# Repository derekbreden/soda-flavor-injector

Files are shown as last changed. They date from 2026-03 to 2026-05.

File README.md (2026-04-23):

# Soda Flavor Injector

ESP32 + RP2040 + ESP32-S3 project that injects flavoring concentrate into cold carbonated water from an under-counter carbonator. Peristaltic pumps duty-cycle based on real-time flow meter readings to maintain consistent flavor strength. A round LCD display shows which flavor is selected, and a separate rotary touchscreen display lets you change flavor images and ratios at runtime.

**[How this got built](how-this-got-built.md)** — the full story, from a failed SodaStream to a working soda machine.

<p align="center">
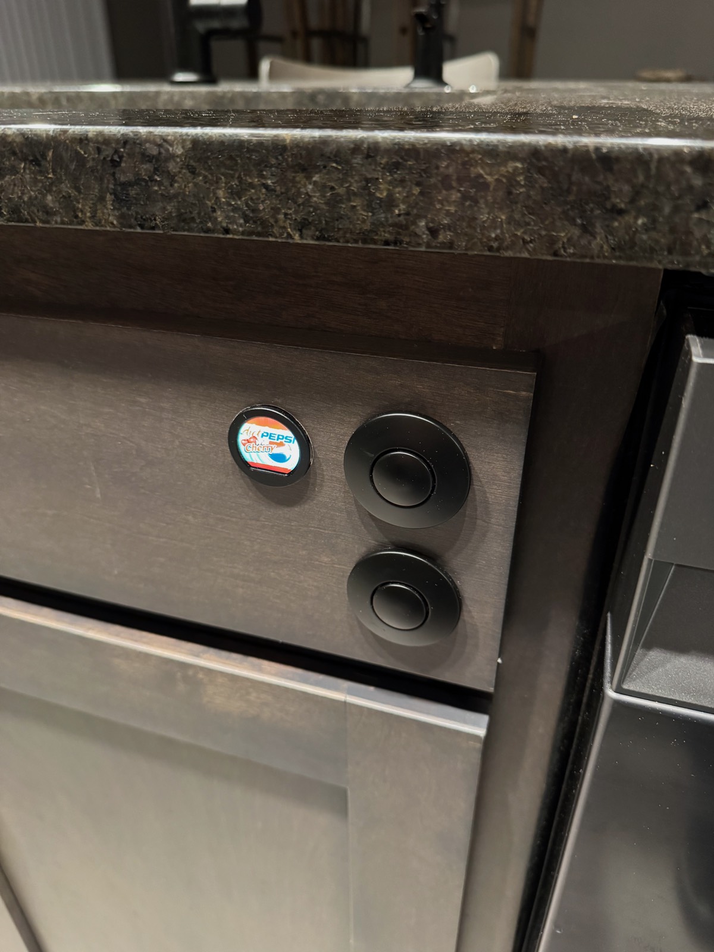
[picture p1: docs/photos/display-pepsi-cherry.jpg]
Front panel showing LCD display with Diet Pepsi Cherry logo and air switch buttons
  
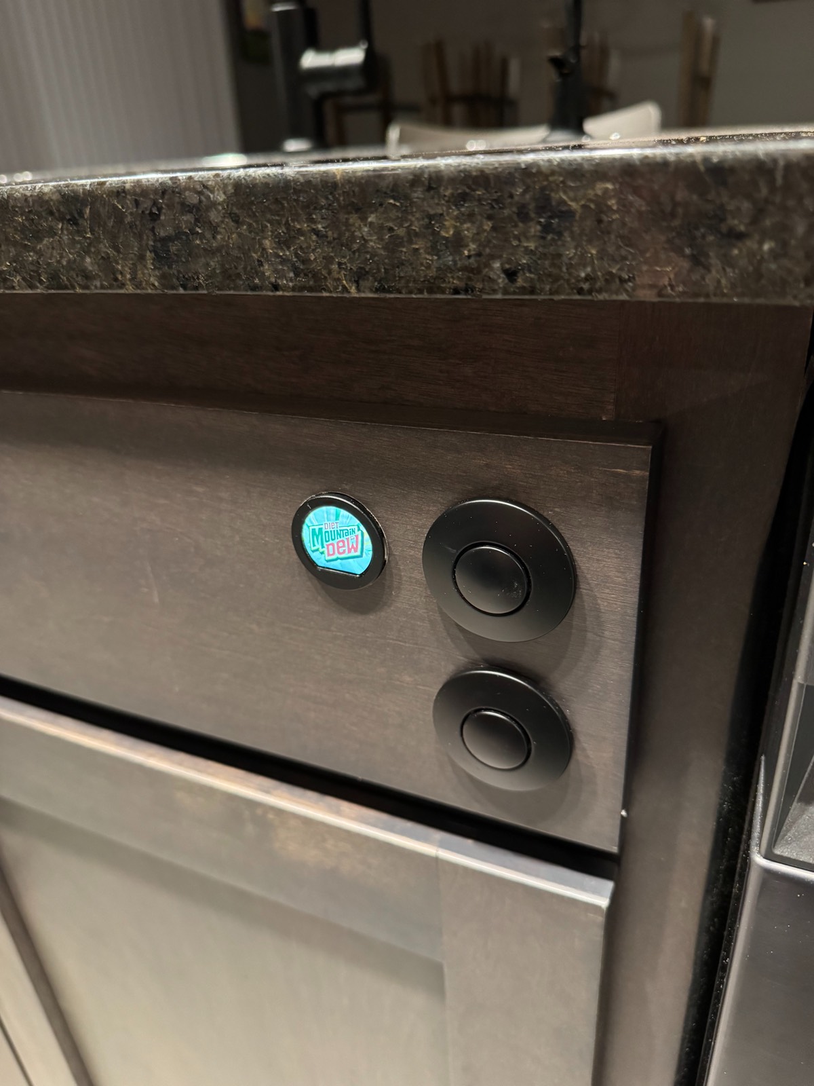
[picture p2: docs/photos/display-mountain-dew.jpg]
Front panel showing LCD display with Diet Mountain Dew logo and air switch buttons
  
</p>
<p align="center"><em>The RP2040 round LCD shows the active flavor. An air switch button toggles between flavors.</em></p>

https://github.com/user-attachments/assets/ddd9bcfd-567e-414a-80be-4f5125431bac

<p align="center"><em>Changing flavor images and ratios on the config display, then pouring a glass with both flavors.</em></p>

## How It Works

Cold carbonated water flows from an under-counter carbonator through a dispenser faucet. When you open the faucet, a flow meter detects water movement and the system automatically kicks in:

1. A solenoid valve opens (it stays closed between uses to prevent backflow and keep the lines primed)
2. A peristaltic pump injects concentrate from a collapsible reservoir
3. The pump duty-cycles on/off proportionally to the detected flow rate
4. Concentrate meets the water stream at the faucet spout

A toggle switch (an air switch) selects between two flavors. The small LCD display updates to show which flavor is active.

<p align="center">
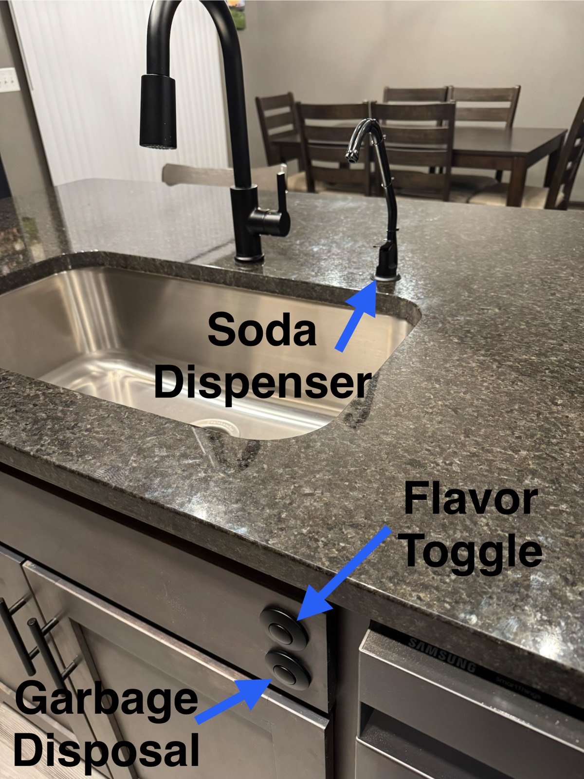
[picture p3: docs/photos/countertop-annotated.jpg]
Kitchen countertop showing soda dispenser faucet and flavor toggle switch
  
</p>
<p align="center"><em>The countertop: a dedicated dispenser faucet and a flavor toggle air switch.</em></p>

### Under the Counter

Everything lives inside the sink cabinet:

<p align="center">
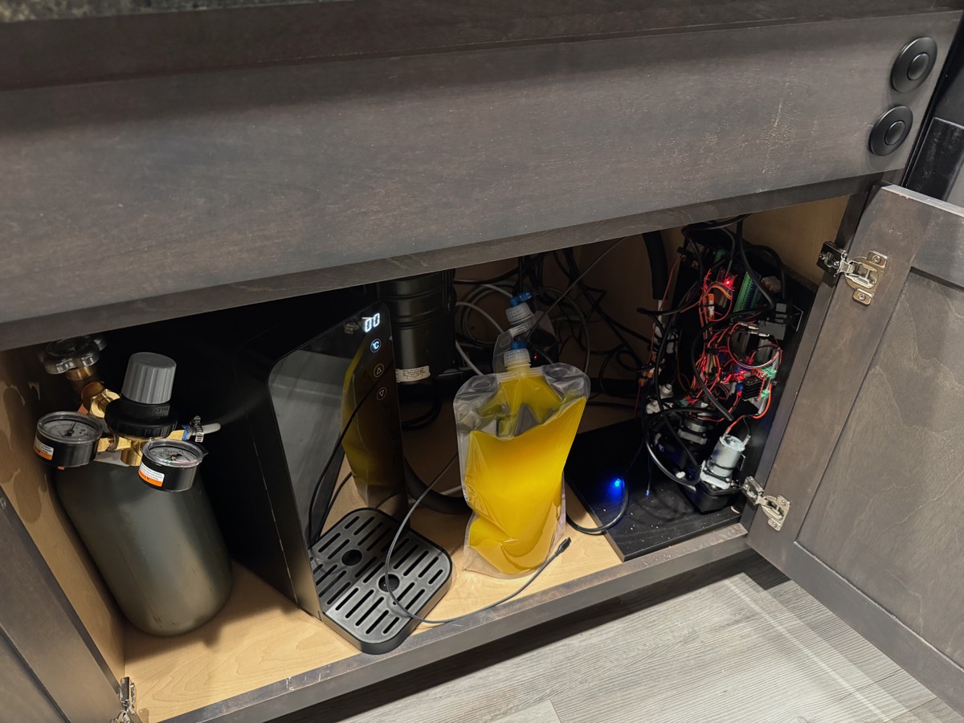
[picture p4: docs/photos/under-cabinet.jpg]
Under-cabinet view showing CO2 tank, carbonator, concentrate bag, and control panel
  
</p>
<p align="center"><em>Left to right: CO2 tank with dual-gauge regulator, Lilium carbonator, Platypus bag filled with concentrate, and the control panel with pumps and valves.</em></p>

Silicone concentrate lines are zip-tied to the outside of the faucet gooseneck:

<p align="center">
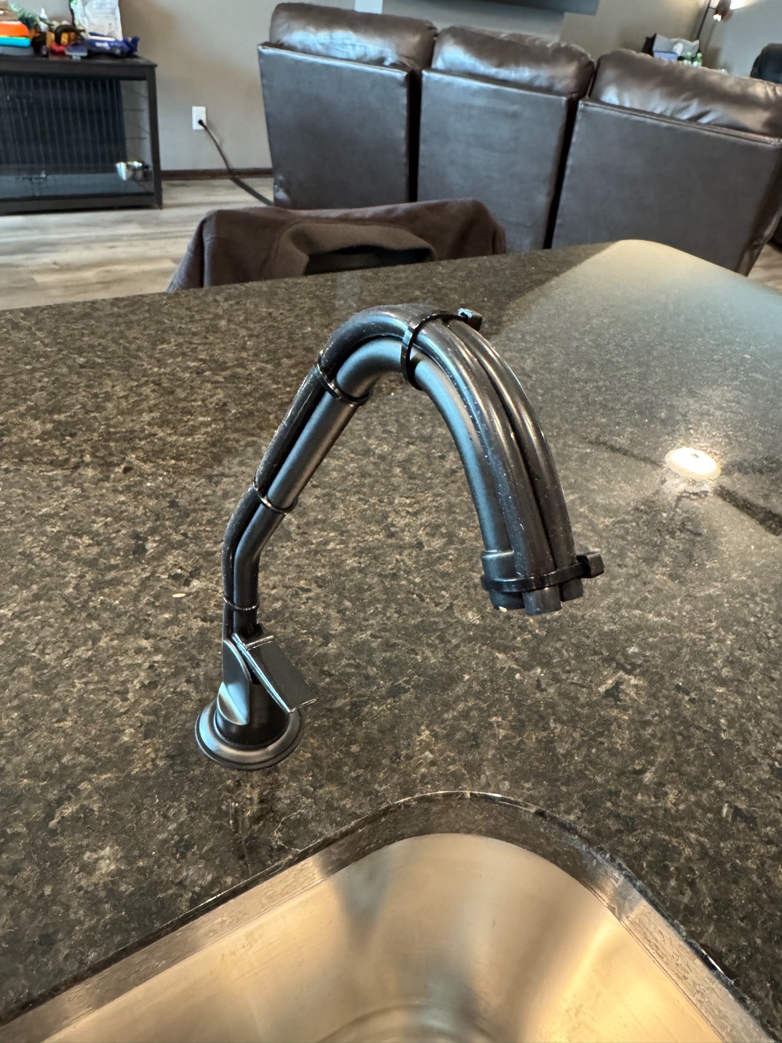
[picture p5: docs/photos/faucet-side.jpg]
Side view of dispenser faucet with silicone tubes bundled along the gooseneck
  
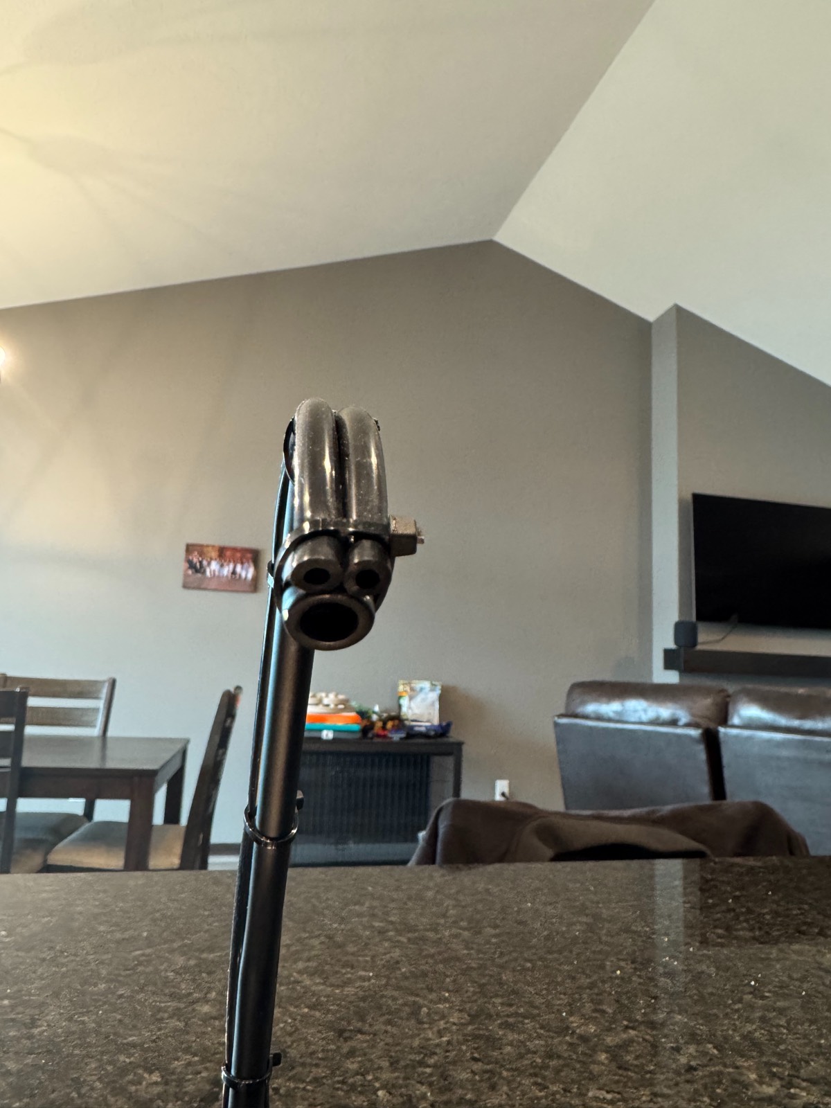
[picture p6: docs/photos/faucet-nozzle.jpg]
Close-up of faucet nozzle showing multi-tube dispensing design
  
</p>

### Architecture

The system runs on three microcontrollers:

- **ESP32** — Main controller. Reads the flow meter, drives pumps and valves via L298N motor drivers, manages the pump state machine, stores config in LittleFS, and coordinates the other boards over UART using TinyProto (HDLC full-duplex reliable delivery).
- **RP2040** (Waveshare RP2040-LCD-0.99) — Display controller. Shows the selected flavor logo on a 128x115 round LCD. Reads the same physical toggle switch for instant visual feedback.
- **ESP32-S3** (Meshnology 1.28" Round Rotary Display) — Config display. A 240x240 round touchscreen with a rotary encoder for changing flavor images and ratios at runtime. Also serves as a BLE bridge between the iOS app and ESP32. Syncs config to the ESP32 over UART.

```
                        ┌─────────────────────┐
  Carbonated Water ───→ │ Flow Meter (GPIO 23) │
                        └──────────┬──────────┘
                                   │ pulses
  ┌───────────────┐     ┌──────────▼──────────┐
  │ ESP32-S3      │     │   ESP32 Controller   │
  │ Config Display│     │                      │
  │ 240x240 touch │◄───►│  Pump State Machine   │
  │ + encoder     │UART │  IDLE → ON → OFF ──→ │──(cycle repeats)
  │               │     │    └── COOLDOWN       │
  └───────────────┘     │    └── PRIME (via UI)  │
                        └──┬────────┬────────┬─┘
                           │        │        │
                      UART │   L298N A  L298N B
                           │   ┌────┴┐  ┌───┴──┐
                           │   │Pump1│  │Pump2 │
              ┌────────────▼┐  │Valve│  │Valve │
              │ RP2040 LCD  │  └─────┘  └──────┘
              │ 128x115 px  │
              │ flavor logo │
              └─────────────┘
```

### Pump Control

The pump doesn't just run at a fixed speed. It duty-cycles (on/off/on/off) with timing that adapts to how fast water is flowing:

| Flow Rate | On Time | Off Time | Duty Cycle |
|---|---|---|---|
| Slow (1 pulse/50ms) | 50ms | 600ms | ~8% |
| Full (6 pulses/50ms) | 200ms | 300ms | ~40% |

This is further scaled by a per-flavor **ratio** parameter (configurable at runtime via the config display):
- Ratio 20 — tuned for SodaStream concentrates (1:20 concentrate-to-water)
- Ratio 6 — for bag-in-box syrup (traditional fountain ratio)

## Parts List

Nearly everything was sourced from Amazon Prime. The only exception is the carbonated water machine.

### Electronics

| Part | Purpose |
|---|---|
| [ESP32-DevKitC-32E](https://www.amazon.com/dp/B09MQJWQN2) | Main controller |
| [ESP32 DIN Rail Breakout Board](https://www.amazon.com/dp/B0BW4SJ5X2) | Clean wiring for ESP32 GPIOs |
| [Waveshare RP2040 Round LCD (0.99")](https://www.amazon.com/dp/B0CTSPYND2) | Flavor display (128x115 GC9107) |
| [Meshnology ESP32-S3 1.28" Round Rotary Display](https://www.amazon.com/dp/B0G5Q4LXVJ) | Config display (240x240 GC9A01A, touch + encoder) |
| [L298N Dual H-Bridge Motor Driver](https://www.amazon.com/dp/B0C5JCF5RS) x2 (link is a 4-pack) | Drive pumps and solenoid valves |
| [12V 2A Power Supply](https://www.amazon.com/dp/B0DZGTTBGZ) | Powers pumps and valves |

### Pumps and Valves

| Part | Purpose |
|---|---|
| [Kamoer Peristaltic Pump (400ml/min, 12V)](https://www.amazon.com/dp/B09MS6C91D) x2 | Dispense flavor concentrate |
| [Beduan 12V Solenoid Valve (1/4")](https://www.amazon.com/dp/B07NWCQJK9) x2 | Prevent backflow, keep concentrate lines primed |

### Sensors and Switches

| Part | Purpose |
|---|---|
| [DIGITEN G3/8" Hall Effect Flow Sensor](https://www.amazon.com/dp/B07QQW4C7R) | Measure water flow rate |
| [KRAUS Garbage Disposal Air Switch (Matte Black)](https://www.amazon.com/dp/B096319GMV) | Flavor toggle (countertop safe, no electricity) |

### Plumbing

| Part | Purpose |
|---|---|
| [Westbrass Cold Water Dispenser Faucet (Matte Black)](https://www.amazon.com/dp/B07KH285GJ) | Dispensing tap at the counter |
| [Platypus 2L Collapsible Bottle](https://www.amazon.com/dp/B000J2KEGY) x2 | Flavor concentrate reservoirs |
| [Platypus Hydration Drink Tube Kit](https://www.amazon.com/dp/B07N1T6LNW) | Tubing + bite valve for reservoirs |
| 1/4" OD Hard Tubing (PE/PU) | All internal plumbing connections (John Guest push-to-connect fittings) |
| [Silicone Tubing (1/8" ID x 1/4" OD)](https://www.amazon.com/dp/B0BM4KQ6RT) | Pump heads, faucet cosmetic run, cable gland pass-throughs, vibration-dampening segments |
| [Waterdrop 15UC-UF Inline Water Filter](https://www.amazon.com/dp/B085G9TZ4L) | Filters water before carbonation |

### Flavor Concentrates

| Part | Notes |
|---|---|
| [SodaStream Pepsi Wild Cherry Zero Sugar](https://www.amazon.com/dp/B0G4NRDQB8) | Default ratio 1:20 |
| [SodaStream Diet MTN Dew](https://www.amazon.com/dp/B0CS191QMW) | Default ratio 1:20 |

### Wiring and Connectors

| Part | Purpose |
|---|---|
| [Dupont Jumper Wires (120-pack M/F, M/M, F/F)](https://www.amazon.com/dp/B0BRTJXND9) | Board-to-board connections |
| [Female Spade Crimp Terminals (60-pack)](https://www.amazon.com/dp/B0B9MZJ2ML) | Motor and valve connections |
| [Male Quick Disconnect Spade Connectors (100-pack)](https://www.amazon.com/dp/B01MZZGAJP) | Motor and valve connections |

### Mounting and Hardware

| Part | Purpose |
|---|---|
| [Zip Ties (200-pack)](https://www.amazon.com/dp/B0BC1VH4XB) | Secure tubing to faucet, cable management |
| [12"x24" Laminate Shelf](https://www.homedepot.com/p/328395734) | Cut in half and screwed together as mounting panel |
| [#8 x 1/2" Wood Screws (100-pack)](https://www.homedepot.com/p/204275505) | Mount components to panel |
| ~~[Pre-wired 12V LEDs (120-pack, 6 colors)](https://www.amazon.com/dp/B07PVVL2S6)~~ | ~~Flavor indicator LEDs~~ (removed — RP2040 display replaced LEDs) |

### Carbonated Water

| Part | Purpose |
|---|---|
| [Lilium Under-Sink Carbonated Water Dispenser](https://liliumfaucet.com/products/under-sink-carbonated-soda-maker-sparkling-water-dispenser-with-3-way-faucet) | Cold carbonated water source (not from Amazon) |
| [TAPRITE Dual-Gauge CO2 Regulator](https://www.amazon.com/dp/B00L38DRD0) | CO2 pressure regulation |
| 5 lb CO2 Tank + First Refill | CO2 source (refills ~$25 at welding/homebrew shops) |

### Tools

Most builders will already have these on hand.

| Tool | Purpose |
|---|---|
| [RYOBI ONE+ 18V Drill/Driver Kit](https://www.homedepot.com/p/326680222) | Drilling and driving screws |
| [RYOBI Drill Bit Set (15-piece)](https://www.homedepot.com/p/315853368) | General-purpose drill bits |
| [Milwaukee 1-1/4" Hole Dozer with Arbor](https://www.homedepot.com/p/202327734) | Countertop holes for faucet and air switch |
| [Wiss 10" Tradesmen Scissors](https://www.homedepot.com/p/313487663) | Cutting tubing and zip ties |
| [Husky Precision Screwdriver Set (7-piece)](https://www.homedepot.com/p/302435926) | Electronics work |
| [Klein Tools 3005CR Ratcheting Crimper (10-22 AWG)](https://www.amazon.com/dp/B07WMB61J5) | Crimp spade terminals |
| [Apple USB-C to USB-C Cable (2m)](https://www.amazon.com/dp/B0DCH5B2HF) | Flash the RP2040 |
| [LISEN USB-C to Micro USB Cable (2-pack)](https://www.amazon.com/dp/B0D3BXM91B) | Flash the ESP32 |

## Wiring

<p align="center">
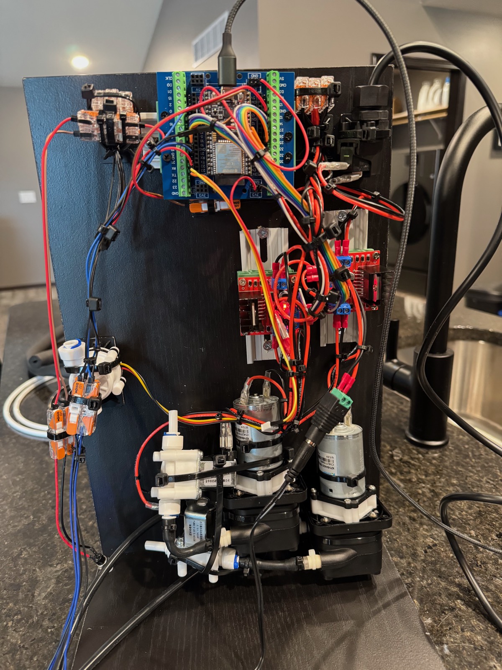
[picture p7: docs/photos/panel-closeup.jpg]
Control panel showing ESP32 on DIN rail breakout, two L298N motor drivers, peristaltic pumps, and solenoid valves
  
</p>
<p align="center"><em>The control panel: ESP32 on a DIN rail breakout board (top), two L298N motor drivers (red boards), two Kamoer peristaltic pumps, and two solenoid valves (bottom).</em></p>

### ESP32 Pin Assignments

**L298N Board A (Flavor 1):**

| Function | GPIO | Notes |
|---|---|---|
| ENA (pump PWM) | 33 | |
| IN1 (pump dir) | 25 | |
| IN2 (pump dir) | 26 | |
| ENB (valve on/off) | 12 | IN3/IN4 hardwired on board (IN3→5V, IN4→GND) |

**L298N Board B (Flavor 2):**

| Function | GPIO | Notes |
|---|---|---|
| ENA (pump PWM) | 19 | |
| IN1 (pump dir) | 18 | |
| IN2 (pump dir) | 5 | |
| ENB (valve on/off) | 4 | IN3/IN4 hardwired on board (IN3→5V, IN4→GND) |

**Inputs and Communication:**

| Function | GPIO | Notes |
|---|---|---|
| Flavor toggle switch | 13 | Air switch, INPUT_PULLUP |
| Flow meter | 23 | Hall effect, FALLING edge interrupt |
| Display UART TX | 32 | 115200 baud, TinyProto HDLC to RP2040 (Serial2) |
| Display UART RX | 35 | 115200 baud, TinyProto HDLC from RP2040 |
| Config UART TX | 15 | 115200 baud, TinyProto HDLC to ESP32-S3 (Serial1) |
| Config UART RX | 34 | 115200 baud, TinyProto HDLC from ESP32-S3 (input-only pin) |

| RTC SDA (DS3231) | 21 | I2C, Wire library |
| RTC SCL (DS3231) | 22 | I2C, Wire library |

**Freed GPIOs** (LEDs removed, valve IN3/IN4 hardwired): 2, 27, 17, 16. GPIOs 27 and 17 are reserved for clean cycle solenoids (L298N Board #3).

### RP2040 Pin Assignments

| Function | GPIO | Notes |
|---|---|---|
| Flavor toggle switch | 29 | Same physical switch as ESP32 |
| UART TX (to ESP32) | 27 | PIO-based serial, 115200 baud, TinyProto HDLC |
| UART RX (from ESP32) | 26 | PIO-based serial, 115200 baud, TinyProto HDLC |
| LCD DC | 8 | Fixed on board |
| LCD CS | 9 | Fixed on board |
| LCD CLK | 10 | Fixed on board |
| LCD DIN | 11 | Fixed on board |
| LCD RST | 13 | Fixed on board |
| LCD Backlight | 25 | Fixed on board |

### ESP32-S3 Pin Assignments (Meshnology 1.28")

All pins are fixed by the board design.

| Function | GPIO | Notes |
|---|---|---|
| LCD SPI MOSI | 11 | GC9A01A, 240x240 |
| LCD SPI SCLK | 10 | |
| LCD CS | 9 | |
| LCD DC | 3 | |
| LCD RST | 14 | |
| LCD Backlight | 46 | |
| Display power 1 | 1 | Must be set HIGH |
| Display power 2 | 2 | Must be set HIGH |
| Touch SDA | 6 | CST816D, Wire1 I2C |
| Touch SCL | 7 | |
| Touch INT | 5 | |
| Touch RST | 13 | |
| Encoder CLK | 45 | |
| Encoder DT | 42 | |
| Encoder BTN | 41 | |
| RGB LEDs | 48 | WS2812 x5 (unused) |
| UART TX (J34) | 43 | 115200 baud, TinyProto HDLC to ESP32 |
| UART RX (J34) | 44 | 115200 baud, TinyProto HDLC from ESP32 |

### Inter-Board Communication

All inter-MCU communication uses [TinyProto](https://github.com/lexus2k/tinyproto) at 115200 baud with HDLC full-duplex framing. Text commands are sent inside `MSG_TEXT` messages; binary image uploads use a state-based protocol where TinyProto handles fragmentation, ACKs, and retransmission internally.

**ESP32 ↔ RP2040 (bidirectional, Serial2, GPIO 32 TX / GPIO 35 RX):**

The ESP32 pushes flavor images, label mappings, and config to the RP2040. The RP2040 sends `MSG_DEVICE_READY` at boot with its image count, triggering a full sync. The ESP32 also re-syncs periodically (every 30 seconds) as a safety net.

**ESP32 ↔ ESP32-S3 (bidirectional, Serial1, GPIO 15 TX / GPIO 34 RX):**

The ESP32-S3 config display communicates with the ESP32 to read and write runtime configuration. The ESP32 is the single source of truth; config is persisted in LittleFS. The S3 also acts as a BLE bridge, forwarding commands from the iOS app to the ESP32.

Text commands are wrapped in `MSG_TEXT` messages. On boot, the S3 sends `GET_CONFIG` until the ESP32 responds. When the user changes a value on the config display (or via the iOS app over BLE), the S3 sends `SET:` followed by `SAVE`.

```
S3 → ESP32:  GET_CONFIG
ESP32 → S3:  CONFIG:F1_RATIO=20,F2_RATIO=20,F1_IMAGE=0,F2_IMAGE=1,numImages=3

S3 → ESP32:  SET:F1_RATIO=18
ESP32 → S3:  OK:F1_RATIO=18

S3 → ESP32:  SET:F1_IMAGE=2
ESP32 → S3:  OK:F1_IMAGE=2

S3 → ESP32:  SET:F1_RATIO=30
ESP32 → S3:  ERR:F1_RATIO out of range

S3 → ESP32:  SAVE
ESP32 → S3:  OK:SAVED              (persists to LittleFS)
```

Valid keys and ranges: `F1_RATIO` (6-24), `F2_RATIO` (6-24), `F1_IMAGE` (0-NUM_IMAGES-1), `F2_IMAGE` (0-NUM_IMAGES-1). The same text commands work over USB serial (115200 baud) for testing.

Boot order does not matter. The S3 retries `GET_CONFIG` until the ESP32 is ready. Both the RP2040 and S3 send `MSG_DEVICE_READY` at the end of their `setup()`, and the ESP32 uses this to trigger initial sync.

## Building and Flashing

This is a [PlatformIO](https://platformio.org/) project with three build environments.

### Flash the ESP32 (main controller)

```bash
pio run -e esp32dev -t upload
```

### Flash the RP2040 (display)

```bash
pio run -e rp2040_display -t upload
```

The RP2040 uses the [earlephilhower Arduino core](https://github.com/earlephilhower/arduino-pico) and the [GFX Library for Arduino](https://github.com/moononournation/Arduino_GFX) for the GC9107 LCD driver.

### Flash the ESP32-S3 (config display)

```bash
pio run -e esp32s3_config -t upload
```

The ESP32-S3 uses the [pioarduino platform](https://github.com/pioarduino/platform-espressif32) for Arduino core 3.x support, [LVGL v8.4](https://github.com/lvgl/lvgl) for the UI, and the [GFX Library for Arduino](https://github.com/moononournation/Arduino_GFX) for the GC9A01A display driver. A custom 64px Montserrat font (`src_config/font_ratio_64.h`) is used for the ratio edit screen.

### Adding a New Flavor Image

Flavor images can be uploaded at runtime from the iOS app over BLE. The iOS app resizes images to the correct dimensions (128x115 for RP2040, 240x240 for S3), converts them to RGB565 format, and uploads them over the framed BLE/UART protocol. Images are stored in LittleFS on each device and survive power cycles.

Factory default images are compiled into the ESP32 firmware via `board_build.embed_txtfiles` and pushed to devices on first boot.

**Adding a new factory default image:**

1. Place the source PNG in `tools/` and run `python tools/png_to_rgb565.py` to generate RGB565 binary files
2. Add the binary files to `data/` for LittleFS upload
3. Update the factory defaults configuration

## Configuration

### Runtime Config (via iOS App, Config Display, or USB Serial)

Flavor ratios and display image assignments are stored in the ESP32's LittleFS filesystem and can be changed at runtime using the ESP32-S3 config display, the iOS app (over BLE), or by sending commands over USB serial:

| Parameter | Range | Default | Description |
|---|---|---|---|
| F1_RATIO | 6-24 | 20 | Flavor 1 concentrate-to-water ratio (lower = stronger) |
| F2_RATIO | 6-24 | 20 | Flavor 2 concentrate-to-water ratio |
| F1_IMAGE | 0-N | 0 | Flavor 1 display image index (images uploadable via iOS app) |
| F2_IMAGE | 0-N | 1 | Flavor 2 display image index |

To change config over USB serial (115200 baud), connect to the ESP32 and send text commands like `SET:F1_RATIO=18` followed by `SAVE`. Send `GET_CONFIG` to see current values.

### Compile-Time Tuning

These control the pump duty cycle shape and generally don't need adjustment. They are `#define`s at the top of `src/main.cpp`:

```cpp
#define PUMP_ON_MIN_MS     50    // minimum pump on-time
#define PUMP_OFF_MAX_MS  1000    // maximum pump off-time
#define SHAPE_ON_BASE     20     // base on-time at minimum flow
#define SHAPE_ON_SLOPE    30     // on-time increase per flow pulse
#define SHAPE_OFF_BASE   660     // base off-time at minimum flow
#define SHAPE_OFF_SLOPE   60     // off-time decrease per flow pulse
```

## Cost Breakdown

Prices as of March 2026.

| Part | Price | Qty | Cost |
|---|---:|----:|-----:|
| [ESP32-DevKitC-32E](https://www.amazon.com/dp/B09MQJWQN2) | $11.00 | 1 | $11.00 |
| [ESP32 DIN Rail Breakout Board](https://www.amazon.com/dp/B0BW4SJ5X2) | $25.99 | 1 | $25.99 |
| [Waveshare RP2040 Round LCD (0.99")](https://www.amazon.com/dp/B0CTSPYND2) | $23.99 | 1 | $23.99 |
| [Meshnology ESP32-S3 1.28" Round Rotary Display](https://www.amazon.com/dp/B0G5Q4LXVJ) | $47.76 | 1 | $47.76 |
| [L298N Motor Driver (4-pack)](https://www.amazon.com/dp/B0C5JCF5RS) | $9.99 | 1 | $9.99 |
| [12V 2A Power Supply](https://www.amazon.com/dp/B0DZGTTBGZ) | $9.99 | 1 | $9.99 |
| [Kamoer Peristaltic Pump](https://www.amazon.com/dp/B09MS6C91D) | $32.55 | 2 | $65.10 |
| [Beduan 12V Solenoid Valve](https://www.amazon.com/dp/B07NWCQJK9) | $8.99 | 2 | $17.98 |
| [DIGITEN Flow Sensor](https://www.amazon.com/dp/B07QQW4C7R) | $7.99 | 1 | $7.99 |
| [KRAUS Air Switch](https://www.amazon.com/dp/B096319GMV) | $39.95 | 1 | $39.95 |
| [7mm Momentary Push Buttons (12-pack)](https://www.amazon.com/dp/B0F43GYWJ6) | $7.39 | 1 | $7.39 |
| [Westbrass Dispenser Faucet](https://www.amazon.com/dp/B07KH285GJ) | $31.28 | 1 | $31.28 |
| [Platypus 2L Collapsible Bottle](https://www.amazon.com/dp/B000J2KEGY) | $15.94 | 2 | $31.88 |
| [Platypus Drink Tube Kit](https://www.amazon.com/dp/B07N1T6LNW) | $24.95 | 1 | $24.95 |
| 1/4" OD Hard Tubing (25ft roll) | ~$9.00 | 1 | ~$9 |
| [Silicone Tubing (6m)](https://www.amazon.com/dp/B0BM4KQ6RT) | $12.99 | 1 | $12.99 |
| [Waterdrop Inline Water Filter](https://www.amazon.com/dp/B085G9TZ4L) | $62.99 | 1 | $62.99 |
| [Dupont Jumper Wires (120-pack)](https://www.amazon.com/dp/B0BRTJXND9) | $5.97 | 1 | $5.97 |
| [Female Spade Crimp Terminals (60-pack)](https://www.amazon.com/dp/B0B9MZJ2ML) | $9.99 | 1 | $9.99 |
| [Male Spade Connectors (100-pack)](https://www.amazon.com/dp/B01MZZGAJP) | $5.99 | 1 | $5.99 |
| [TAPRITE CO2 Regulator](https://www.amazon.com/dp/B00L38DRD0) | $92.95 | 1 | $92.95 |
| 5 lb CO2 Tank + First Refill | $139.00 | 1 | $139.00 |
| [Zip Ties (200-pack)](https://www.amazon.com/dp/B0BC1VH4XB) | $3.99 | 1 | $3.99 |
| [12"x24" Laminate Shelf](https://www.homedepot.com/p/328395734) | $12.98 | 1 | $12.98 |
| [#8 x 1/2" Wood Screws (100-pack)](https://www.homedepot.com/p/204275505) | $6.87 | 1 | $6.87 |
| [SodaStream Pepsi Wild Cherry (4-pack)](https://www.amazon.com/dp/B0G4NRDQB8) | $28.99 | 1 | $28.99 |
| [SodaStream Diet MTN Dew (4-pack)](https://www.amazon.com/dp/B0CS191QMW) | ~$29 | 1 | ~$29 |
| **Subtotal (without carbonator)** | | | **~$775** |
| [Lilium Under-Sink Carbonator](https://liliumfaucet.com/products/under-sink-carbonated-soda-maker-sparkling-water-dispenser-with-3-way-faucet) | $1,039.00 | 1 | $1,039.00 |
| **Subtotal (all parts)** | | | **~$1,814** |
| *Tools (if not already owned):* | | | |
| [RYOBI Drill/Driver Kit](https://www.homedepot.com/p/326680222) | $49.97 | 1 | $49.97 |
| [RYOBI Drill Bit Set (15-piece)](https://www.homedepot.com/p/315853368) | $12.97 | 1 | $12.97 |
| [Milwaukee 1-1/4" Hole Dozer with Arbor](https://www.homedepot.com/p/202327734) | $16.47 | 1 | $16.47 |
| [Wiss 10" Tradesmen Scissors](https://www.homedepot.com/p/313487663) | $21.97 | 1 | $21.97 |
| [Husky Precision Screwdriver Set](https://www.homedepot.com/p/302435926) | $4.88 | 1 | $4.88 |
| [Klein Tools 3005CR Ratcheting Crimper](https://www.amazon.com/dp/B07WMB61J5) | $34.96 | 1 | $34.96 |
| [Apple USB-C to USB-C Cable (2m)](https://www.amazon.com/dp/B0DCH5B2HF) | $18.00 | 1 | $18.00 |
| [LISEN USB-C to Micro USB Cable (2-pack)](https://www.amazon.com/dp/B0D3BXM91B) | $7.59 | 1 | $7.59 |
| **Total (with tools)** | | | **~$1,981** |

## License

MIT

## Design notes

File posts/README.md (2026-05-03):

# Posts

Daily Updates feed for homesodamachine.com/blog. Each markdown file in this
directory is one day's post. Posts are committed to git like any other
file; on deploy, the server hashes every `posts/*.md`, diffs against the
`post_hashes` table in Postgres, and fires an FCM push notification per
new or changed post (see `lib/push.js`). The post's frontmatter title is
the notification heading. Treat committing a new post as a publish action
— it pages every subscriber.

## The format

Filename: `posts/YYYY-MM-DD-HHMM.md` where HHMM is the time of the latest
commit covered, in 24-hour US Central time.

Frontmatter:

```yaml
---
date: <ISO-8601 timestamp of the latest commit covered, with -05:00 offset>
title: <short noun phrase, 2–5 words, like "Faucet and Site">
covers_from: <`git rev-parse <oldest-commit-covered>^`>
covers_through: <hash of newest commit covered>
---
```

Body: a flat bullet list. **1–3 top-level categories. 2 is the sweet
spot.** Each category has this exact shape:

```
- <headline, 8 words or fewer>
  - Before today <state, ~5–15 words>
  - After today, <state, ~10–25 words>
```

If "after" splits cleanly into 2–4 distinct things, expand it:

```
  - After today, it has:
    - <thing>
    - <thing>
    - <thing>
```

**Collapsing "did not exist".** Always draft each category in the full
before/after form first. On a final pass, if the before-line is "this
part did not exist" (or equivalent null state: "had no spec," "did not
exist yet") AND the after expands into a sub-list, drop the
before/after labels entirely — the headline plus the sub-list carry
the change. Apply this only when the before-state is the trivial null.
Example:

```
- The carbonator got an insulating shell
  - Before today this part did not exist
  - After today, it has:
    - An inner cylinder hugging the cold tank with a foam gap
    - An outer cylinder with cradle pockets for the two flavor bags
    - A split into a bottom cup and an upper shell that nest together for printing
```

collapses to

```
- The carbonator got an insulating shell
  - An inner cylinder hugging the cold tank with a foam gap
  - An outer cylinder with cradle pockets for the two flavor bags
  - A split into a bottom cup and an upper shell that nest together for printing
```

Do not collapse when the before describes specific prior state ("we had
not got to the lever yet," "the link was a hand-rolled reliability
layer"). The before/after labels are carrying meaning there.

That is the entire format. No prose paragraphs. No headline arcs. No
"also today" tail.

A 2-category post is ~70 words. 3 categories is ~110 words. If you're at
150+, you're padding.

## What to do

### Day narrative, not diff narrative

You are describing what happened in the world today, not what landed
in the repo. This is a real physical project being built in a garage;
commits are evidence of activity, not the activity itself. A single
commit that adds a dated snapshot in `hardware/` or `marketing/`
(e.g. `welding-progress-*.md`, `build-readiness-*.md`,
`first-weld.md`) can represent days or weeks of off-repo work — read
it fully and weigh it as a candidate category, not as "docs cleanup."
A one-line ledger update saying "X1 Pro arrived" is a heavier
real-world inflection than 22 viewer commits. Reconstruct the day
from the user's perspective: what did they *do* today, what
capability is new in their world, what would they tell someone in
person tonight?

### Categorize by outcome, not activity

This is the rule you will get wrong if you forget anything else. You are
reporting **what is true now that wasn't true before**, not what was
attempted along the way. Group commits by what visibly changed in the
project — what a stranger would recognize as one thing — even if it took
30 commits across many files and many sub-arcs.

- Right: "the printed faucet got more complete" — one category,
  regardless of how many sub-tasks it contained.
- Wrong: "the lever was finalized; the back wall went in; the cutouts
  shrank; the material changed" — four activities, not four outcomes.

Before/after lines describe **state**:

- Right: "Before today we had not got to the lever yet."
- Wrong: "Lever ramp finalized as 18° wedge."

The threshold for whether something earns a category is **relative to
the window**. A small hardware tweak doesn't earn a slot if there are
already two strong outcomes, but it absolutely does if the day is
otherwise quiet — a one-bullet-only day looks malnourished. The decision
is always "what's the best 1–3 bullet picture of this window," not "what
passes an absolute bar."

### Voice

Match the gold-standard posts (see Examples). Specifically:

- Conversational first-person plural ("we got past", "we have")
- Colloquial grammar where natural ("had not got")
- Concrete specifics: numbers, counts, what concretely changed
- Parenthetical translations on first use of brand or technical terms a
  stranger wouldn't know: "STEP file (3D drawing)", "Mermaid file
  (flowchart)", "BLE (Bluetooth)"
- **Each post must stand alone.** No "yesterday," no implicit references
  to prior posts. A reader landing cold needs enough to track.
- Past tense for completed work, present tense if the work is genuinely
  mid-flight at the end of the window
- **Headlines lead with subjects, not verbs.** "HomeSodaMachine.com is
  now a live site." Not "Started a rear-panel nameplate." Verb-led
  headlines describe activity; you want state.
- **Sub-bullets in the expanded form are noun phrases, not full
  sentences.** "A polished iOS-style look." Not "The pump tray and
  coupler tray widened to 170mm."
- **Title is "X and Y" — no commas.** "Faucet and Site." Not
  "Pump Case, Strut, iOS."
- **Three sub-bullets in the expanded form.** Two reads thin, four reads
  dense. Three is calibrated.
- **Before-line ≤15 words, plain verbs.** "Before today we had not got
  to the lever yet." Avoid "consisted of," "had been engineered to,"
  25-word setups.
- **Small/punchy first, big/expanded second.** Put the heavier
  expanded-form category at the bottom of the post.

### What's banned

- Project-internal jargon: zone numbers (`Zone 4`, `ZONE4_Z_TOP`),
  CadQuery API names (`loft`, `ruled=False`, `copyWorkplane`), function
  names, file paths, code identifiers, code-named parts
- Journey language: "ten hours of attempts," "after three reverts,"
  "wrestled with X"
- Marketing voice: "exciting," "shipped 🚀," emoji, "huge," "stay
  tuned," "milestone"
- References to yourself, to the routine, or to the date in prose (the
  date is in frontmatter)

### Project terminology

Use the project's canonical terms. The two most-confused:

- **Bill of materials**, not "parts list." The file is `hardware/bom.md`
  and its H1 is "Bill of Materials — One Consumer Unit." Commit messages
  use the `bom:` prefix. The README's "Parts List" section is a separate
  Amazon-shopping framing for outside readers — not the engineering
  source of truth. The abbreviation "BOM" is fine in titles for
  terseness; spell out "bill of materials" in body prose.
- **The carbonator's foam shell**, not "flavor reservoir housing." The
  foam-bag-shell (`hardware/printed-parts/foam-bag-shell/`) wraps the
  carbonator tank and includes pockets for the soft flavor bags. The
  plan-b hardshell flavor reservoir
  (`hardware/printed-parts/plan-b/reservoir/`) is a different concept
  that landed as docs only on 2026-05-02 — don't conflate them in earlier
  posts.

### Skip rules

If the window is only formatting, dependency bumps, comment-only edits,
or `chore:` cleanups: skip the post entirely (don't write a file). If
only one substantive commit: write a single-bullet post on it. If the
day has zero commits: skip and report.

### When you don't have full context

If something looks like a project-naming or terminology question and
you're not sure ("is this part really called X or Y?"): **don't guess
and don't reflexively defer to the agent that drafted it either.** Read
`hardware/bom.md`, `hardware/future.md`, the part's own README, and
recent commit messages. Prior posts in this directory are also a strong
signal of established naming. If still ambiguous after that, ask the
user before writing.

Use the term that was canonical on the post's date — not the term
that's canonical now. The repo evolves; the post is anchored to its
window. A part renamed three weeks after the post window should still
appear under its earlier name. Same for capabilities: don't pull
later-acquired terminology ("Plan A", "the printed reservoir", "the
website") into windows where those concepts didn't exist yet.

## Procedure

1. Find the day's commits:

   ```
   git log --since="<DATE> 00:00 -0500" --until="<NEXT_DATE> 00:00 -0500" \
     --pretty=format:"%h %ai %s"
   ```

2. Read the diffs for substantive commits — `git show <hash>` per file
   that changed substantively. Commit messages are summaries, not
   truth; a subject like "Revert experimentation back to ruled=False
   side lofts" is meaningless until you see the diff.

3. Group commits into 1–3 outcomes. Collapse aggressively. Skip the
   reverts, the bisection sweeps, the "Had to remake your commit sorry"
   commits — those belong inside the arc they're part of, not as
   separate items.

4. Write the post to `posts/YYYY-MM-DD-HHMM.md`. Verify each headline
   is 8 words or fewer (this is the rule that drifts most often). Verify
   the post stands alone — no "yesterday," no references to the prior
   day's post.

5. Don't auto-commit unless explicitly instructed. The act of committing
   pages every subscriber, so a human review pass before publish is the
   default.

## Examples

These two posts were calibrated through several rounds with the project
owner. Match this voice exactly. If your draft is twice as long, or has
a prose paragraph anywhere, or starts using zone numbers, something has
drifted.

- `posts/2026-04-29-2238.md` — the canonical 2-category post.
- `posts/2026-05-01-1703.md` — second gold standard.

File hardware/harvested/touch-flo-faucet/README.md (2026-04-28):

# Touch-Flo Faucet Teardown + Fabrication Plan

The dispense point of this appliance is a custom three-tube spout (1× carbonated water + 2× flavor) with a factory-grade self-closing spring-piston lever valve harvested from a Touch-Flo–class cold water dispenser faucet. Mixing occurs in the user's glass, not before — see `hardware/requirements.md`. This directory captures the harvest donor, the class of mechanism being harvested, and the fabrication plan for the spout.

## Why harvest

The self-closing spring-return poppet valve on a Touch-Flo faucet is the only off-the-shelf subassembly found that gives consumer-appliance-grade lever action with a clean return-to-closed, in a form factor that mounts through a deck. It is a spring-piston poppet against a silicone seat — not a ceramic disc cartridge. Target patent class: Crystal Mountain US8857669B2.

Building this mechanism from scratch is possible but displaces attention from the rest of the machine. Modifying a three-way faucet (removing the two unwanted knobs) leaves visible plugged bosses. Harvesting the Touch-Flo lever assembly and re-clothing it with our own three-tube spout avoids both problems.

## Harvest donor (primary)

**Westbrass R2031-NL-12 Touch-Flo cold water dispenser faucet** — ASIN `B01N5LVNQA`, ~$19.53, Prime Two-Day.

- Picked as the cheapest Prime-available Touch-Flo for the prototype round — we want a repeatable pattern, not a specific brand. Any Touch-Flo–class faucet with a spring-piston poppet cartridge and a 1/4" compression inlet is substitutable.
- Deck-mount, single-lever, self-closing.
- Inlet: 1/4" compression — matches the project's existing 1/4" compression plumbing; no adapter needed.
- Internal: spring-return poppet against silicone seat (not a ceramic disc cartridge).

The already-owned Westbrass A2031-NL-62 ($32.18) and D203-NL-62 ($52.99) in `hardware/purchases.md` are not the harvest donors — the R2031-NL-12 pattern was chosen after they were purchased, specifically to avoid brand lock-in.

## What gets kept, what gets discarded

**Kept (harvested):**
- Lever
- Entire Touch-Flo body (see valve-body-reference folder)

**Discarded:**
- Mounting plate

## Three-tube spout — fabrication plan

Target end-state: three visible powder coated stainless tubes emerging from the faucet body, bent to dispense over a glass at the sink. Center tube carries carbonated water from the harvested valve. Smaller 1/8 tubes carry flavor from the peristaltic pumps.

- **Center tube:** 3/8" OD 316 SS
- **Rear tubes:** 1/8" OD 316 SS

The asymmetric diameter (3/8" center + 2× 1/8") is the intentional design language — carbonated water is the main event, flavor is the accent.

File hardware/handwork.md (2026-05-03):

# Handwork

Skilled-hand tasks on the path to a finished unit. One person, one unit at a time — the Founder Edition cadence ([target-market.md](../marketing/target-market.md)).

Companion to [bom.md](bom.md) (per-unit parts) and [purchases.md](purchases.md) (every dollar out, with founder time explicitly excluded — "sweat equity, un-booked by design").

Order isn't strict — pressure-testing waits on tap + weld being complete on the same vessel; the others run independently.

## Solder JST connectors to boards

Solder male JST-XH 2.54 mm headers to the carrier boards so the field-crimped female housings (loose terminals + bonded ribbons + Keszoox pre-crimped pigtails) can plug in. Three pin counts per [bom.md §11](bom.md):

- **4-pin** (B0B2RB524Y) — I2C and UART hops between modules (ESP32 ↔ MCP23017, ESP32 ↔ ESP32-S3 UART, ESP32 ↔ RP2040 UART), ~3 connectors per unit.
- **6-pin** (B0B2R8Q1JL) — DS3231 RTC (VCC/GND/SDA/SCL/SQW/32K), ~1 connector per unit.
- **9-pin** (B0B2R73RQB) — ULN2803A module sides (8 channels + COM/GND) and MCP23017 Port A/B rows, ~6 connectors per unit.

Hakko station, 60/40 leaded solder, ESD mat — all already in [purchases.md §14](purchases.md).

## Bend copper around the pressure vessel

Wind the GOORY 1/4" OD × 0.031" wall ACR copper tubing tight around the vessel OD as the evaporator coil. The 0.031" wall resists kink at the bend radius required around the 5" OD vessel. Single-layer wrap at ~1/8" pitch yields ~22 ft of wrap per vessel + ~2 ft each end for compressor and suction-line tie-ins ([bom.md §5](bom.md)). Bonded to the tank OD with 3M 425 aluminum foil tape — applied as a continuous skin under the coil so the tape spans the tank ↔ coil thermal interface ([future.md](future.md) "Refrigeration subsystem").

## Tap NPT in 316L end caps

Hand-tap 1/4"-18 NPT directly into the 1/4"-thick laser-cut 316L end-cap plates from SendCutSend (`endcap-circular-2hole.dxf`). 2 ports per plate × 2 plates per vessel × 10 vessels of stock = 40 holes. Tap Magic EP-Xtra cutting fluid; Drill America HSS pipe tap; Brown & Sharpe spring-loaded tap guide on the WEN drill press; Drill America DWT adjustable tap wrench for the hand drive. The committed plan for the first hole is [tapping-plan-2026-05-03.md](tapping-plan-2026-05-03.md); the remaining 39 follow once that one proves the fixture and the feel.

## Weld 316L end caps to 316L tubes

Join the 1/4"-thick 316L end-cap plates to the 5" OD × 0.065" wall 316L tube ends with the XLaserlab X1 Pro handheld laser welder, STARTECHWELD ER316L .030 filler (matches the 316L parent metal — undermatching with 308L would lose the molybdenum across the joint). Top + bottom plates per vessel × 10 vessels of stock. The 1/8" 316L float rod (Tandefio B0CY4DWJFQ, cut to ~6") tack-welds vertically to the inside face of the bottom plate as part of this same operation, before the bottom-plate-to-tube weld closes the vessel ([future.md](future.md) "Level sensing").

## Pressure-test 316L vessels

Hydro-test each fully welded + tapped vessel to 150 PSI for 30 minutes (~2× the 70 PSI working pressure). Done after tapping and welding are both complete on a given vessel. Beyond the 30-min hydro-test minimum, an in-vessel pressure-test gauge (LIKELY-TO-BUY in [purchases.md](purchases.md)) supports hour-scale leak soaks for catching slow weep before passivation and service.

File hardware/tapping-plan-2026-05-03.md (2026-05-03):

# Tapping plan — Snapshot 2026-05-03

**This is a point-in-time snapshot, not a living document.** Captures the plan committed to on the eve of the first 1/4-18 NPT tap into a 316L endcap plate. The Amazon tooling batch (WEN drill press, Brown & Sharpe tap guide, Drill America tap + wrench, 4-7/8" hole saw, Baltic birch, MDF, C-clamps) was delivered Saturday 2026-05-02 and is sitting unpacked. The single goal for Sunday morning is one successful tap in one plate.

## TL;DR — the six-step plan

The user's own distillation, in their own words:

> - Mount press
> - Set belt speed
> - Cut birch pocket
> - Disc in pocket
> - Load tap guide
> - Wrench the tap

That's the morning. No production cadence. No fixture refinement. One hole.

## Each step, expanded

The expansion below is supporting detail behind the six bullets above — not a separate plan.

### Mount press
C-clamp the WEN 4208T base to one of the VEVOR benches at two opposite corners. Plug in, spin test.

### Set belt speed
Open the cover, drop the belt to slowest speed (740 RPM, smallest motor pulley → largest spindle pulley). This is for the hole-saw cut. Tapping is hand-driven, so the speed setting doesn't matter after this.

### Cut birch pocket
Stack on the table: 1/4" MDF (sacrificial) under, one 12mm Baltic birch piece on top. Mark the Baltic birch center. The 8"×8" stock overhangs the 6.5" table on all sides — two C-clamps grip the overhang down to the table edges. Plunge slow with the 4-7/8" hole saw, retract every 1/4" to clear the chip plug. If the stack walks, the clamps weren't tight; redo them. Drop a 316 disc in. Should sit flush with ~0.015" play. Snug-but-seats is better than loose.

### Disc in pocket
Pull the chewed-up MDF, slide a fresh 1/4" MDF sheet under the pocket piece (the tap will bury into it on breakthrough — that's its job). Disc in pocket. Slide the whole stack until pilot hole #1 is directly under the chuck. Two C-clamps lock the stack to the table.

### Load tap guide
Chuck the Brown & Sharpe spring tap guide. Tap Magic generously into the pilot hole and onto the first inch of the tap. Engage the tap in the pilot. Lower the chuck until the guide tip seats in the tap's center divot, spring compressed ~1/4". Lock the depth or just hold it.

### Wrench the tap
Drill America wrench on the tap. CW, slow. Half turn forward, quarter back to break the chip. Re-fluid every few turns. It gets harder as the taper bites deeper — that's correct, not a problem. Stop after 4–5 full threads of engagement (you'll feel it transition out of the free-cutting phase). Back out clean. Hand-thread any 1/4 NPT fitting in — should snug firm with 2–3 threads showing. Done.

## Provenance — where this came from

Came out of a Claude Code conversation on 2026-05-03 between the user and Claude (Opus 4.7). The user asked Claude to describe Sunday morning assuming the goal was one successful tap before lunch — bullet list, realistic about what would actually get followed, no time estimates, no over-cautioning. Claude returned a four-section plan (Get the press ready / Cut the pocket / Set up to tap / Tap it) with bullet expansion under each. The user reshaped that into the six-bullet form above — splitting Claude's compound titles into atomic ones, and trimming away the "things that might bite you" section as out-of-focus for the morning. The user's six-bullet form is the plan; Claude's expansion is the supporting detail.

The plain-English version: I asked Claude what tomorrow morning looked like. Claude wrote four steps. I wrote six. Mine is the plan.

## What this snapshot is NOT

- Not a fixture-design doc — the morning's fixture is single-use Baltic birch + MDF, not the production fixture for all 40 holes.
- Not a production-cadence commitment — the goal is *one* tap before lunch, not 40.
- Not a substitute for hands-on feel — the tap-binding moment, the right turn-back rhythm, and what "snug firm with 2-3 threads showing" feels like are felt, not read from a doc.

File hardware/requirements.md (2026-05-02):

# Home Soda Machine

## 1. Basic Operation

- Refrigerated carbonated water is provided to a faucet by a built-in carbonator (replacing the external Lillium/Brio units used in the prototype)
- When that flow is detected, we pump flavoring in a parallel line (not the same line as the cold carbonated water)
- There are 2 separate parallel lines, one for each flavor, and each is primed and valve locked so that it is always primed and can be dispensed instantly
- The mixing occurs in the user's cup/glass, not before

## 2. Filling

- The user pours sodastream sucralose sweetened flavoring (no sugar) into a funnel
- That funnel is as close to the front as possible, on the top side of the device
- Liquid in the tubing connected to the funnel is detected via capacitance, and is pumped into the selected flavoring reservoir

## 3. Cleaning

- The user initiates a clean cycle for a flavoring reservoir from the iOS app or S3 interface
- The valve allowing tap water into the reservoir is opened until the reservoir fills with water, then is closed
- That water is pumped through the normal dispensing route from the reservoir
- Air is pumped into the reservoir from the funnel inlet
- That air is pumped through the normal dispensing route from the reservoir
- The cycle is repeated

## 4. Replacement Philosophy

- There are only 2 peristaltic pumps, one dedicated to each flavor, and the valves allow them to be used for multiple purposes
- When the pumps wear out, the user can remove and replace the pump cartridge which contains both pumps
- We aim to avoid replacing anything other than the peristaltic parts during the product's intended lifetime. The target is 10 years; the practical floor is the internal LLDPE hard tubing, where reaching it requires enough disassembly that the appliance is effectively at end-of-life anyway
- Internal wetted parts (reservoirs, foam shell, internal plumbing) are not glued or potted, so a service path exists for owners who choose to keep a unit running past that mark. The 10-year owner is the design target; longer-tail use is allowed by the service paths, not optimized for
- The iOS app and BLE bridge are conveniences, not dependencies. All necessary operation — selection, dispense, fill, cleaning, ratio configuration — is reachable from the appliance's physical interfaces (faucet handle, air switch, S3 display)

## 5. Prototype hardware

The prototype below already accomplishes the dispense path. The integrated-appliance build extends this hardware; see [`future.md`](future.md) for the shipping configuration.

| Part | Qty |
|---|----:|
| [ESP32-DevKitC-32E](https://www.amazon.com/dp/B09MQJWQN2) | 1 |
| [Waveshare RP2040 Round LCD (0.99")](https://www.amazon.com/dp/B0CTSPYND2) | 1 |
| [Meshnology ESP32-S3 1.28" Round Rotary Display](https://www.amazon.com/dp/B0G5Q4LXVJ) | 1 |
| [L298N Motor Driver (4-pack)](https://www.amazon.com/dp/B0C5JCF5RS) | 1 |
| [Kamoer Peristaltic Pump](https://www.amazon.com/dp/B09MS6C91D) | 2 |
| [Beduan 12V Solenoid Valve](https://www.amazon.com/dp/B07NWCQJK9) | 10 |
| [DIGITEN Flow Sensor](https://www.amazon.com/dp/B07QQW4C7R) | 1 |
| [Platypus 2L Collapsible Bottle](https://www.amazon.com/dp/B000J2KEGY) | 2 |
| [Silicone Tubing (6m)](https://www.amazon.com/dp/B0BM4KQ6RT) | 1 |
| [KRAUS Air Switch](https://www.amazon.com/dp/B096319GMV) | 1 |

- The RP2040 is smaller display which looks nice mounted flush with paneling in front of the sink.
- The S3 is a larger display, which has a knob and allows easy changing of flavoring ratios or other settings.
- It is expected that both displays will be mounted into the front of the final device, such that they can be "snapped out" and placed elsewhere, with a retracting 1m or 2m cat6 cable connecting them to the device still, but that that they are flush with the front of the device otherwise.
- The ESP32 will maintain all functionality even if both displays are disconnected entirely.
- Clean and prime each have an internal momentary button wired to the ESP32, so they remain reachable when both displays and the iOS app are unavailable.
- The KRAUS Air Switch is also expected to be mounted and detachable and flush in the exact same fashion as the displays. However, if it is disconnected, the user will be stuck on whatever flavor was last selected.

## 6. Printed parts

- The FDM printer is a Bambu H2C
- Single Nozzle Printing: 325 mm x 320 mm x 320 mm
- Dual Nozzle Printing: 300 mm x 320 mm x 325 mm
- Layer sizes can be as low as 0.1 mm
- Supported materials (standard): PLA, PETG, TPU, PVA, BVOH, ABS, ASA, PC, PA, PET, PPS, PPA
- Supported materials (carbon/glass fiber reinforced): PLA, PETG, PA, PET, PC, ABS, ASA, PPS

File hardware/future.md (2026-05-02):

**Carbonation subsystem**

The carbonator vessel is custom-fabricated from 316L stainless steel and oriented vertically (always vertical, regardless of cross-section choice). 316L was chosen over 304 for the wetted pressure boundary because the molybdenum addition gives meaningfully better pitting and crevice-corrosion resistance in the chloride + carbonic-acid environment of long-life carbonated water service; the cost delta on the small per-vessel quantity was acceptable. Two body geometries are in play:

- **Plan A (current plan):** commodity 5" OD × 0.065" wall 316 welded SS round tube (OnlineMetals part #12498, MTRs required), capped at top and bottom with 1/4"-thick laser-cut 316 SS circular plates from SendCutSend (`endcap-circular-2hole.dxf`). Plates are joined to the tube ends with the XLaserlab X1 Pro handheld laser welder. The 1/4" plate is thick enough to direct-tap 1/4" NPT (4.5 turns of engagement) without weld-in bungs. This is the path being pursued.
- **Plan B (still under exploration):** racetrack body formed from two 7.754" × 6.000" half-blanks in 0.048" 304 SS, press-formed into D-halves and butt-welded along both flat sides; press-domed 0.060" 304 SS racetrack end caps. Retained as fallback if the 1/4"-plate-to-0.065"-tube weld can't be made reliably. Plan B inventory remains 304 SS (existing SendCutSend stock) — accepted inconsistency for a fallback that may never be invoked. Blank DXF in `cut-parts/carbonator-body-sheet/generate_dxf.py`; press die specs and CadQuery script in `printed-parts/carbonator-body-press-dies/`. Racetrack end-cap DXF in `cut-parts/carbonator-endcaps-racetrack/generate_dxf.py`; dishing dies in `printed-parts/carbonator-dishing-dies/`.

Both plans target a working pressure of 70 PSI minimum with adequate margin (plan A: 5" OD × 0.065" wall 316L SS gives hoop stress of ~2,690 PSI at 70 PSI, ~7.4× safety factor vs 20,000 PSI allowable; plan B: 4,058 PSI hoop stress, 4.9× safety factor — same allowable for 304/316L for vessel-grade service). Both are hydro-tested to 150 PSI (~2× working pressure) for 30 minutes before service.

The vessel has exactly four ports, all 1/4" NPT, hand-tapped directly into the 1/4" end plates (plan A) or into welded bungs (plan B fallback only). Tap Magic cutting fluid is used on the SS-into-SS tap.

Port 1 — CO2 inlet to internal sparge stone: A 1/4" hose-barb × 1/4" MNPT 316 SS adapter (LTWFITTING B017N4TTMA) threads into the bottom plate. On the inside face, a short length of food-grade silicone tube connects the barb to a 0.5 µm sintered 316 SS sparge stone (FERRODAY B091C5Y6L9, 1/4" barb input) that hangs in the water column. CO2 enters as fine bubbles that rise through the water, dissolving on the way up — high bubble surface area + short residence time = fast Henry's-law equilibration. Sparge replaces the earlier atomizer plan: the Beduan spiral-cone nozzle requires a high pressure differential across the nozzle to atomize, and at our working ΔP (15–25 PSI between pump output and 70 PSI headspace) it produces a stream, not a spray. Sparging is also mechanically simpler — no precision orifice, no custom-machined parts.

Port 2 — Water inlet (top plate): The SeaFlo diaphragm pump pushes filtered tap water against the CO2 back-pressure into the headspace, free-falling onto the water surface. No atomizer, no dip tube on the inlet side. Path: pump 3/8" hose barb → MAACFLOW 3/8" barb × 1/4" NPT SS adapter (B0DMP77B6S) → GASHER 1/4" NPT SS PTFE-soft-seat check valve → 1/4" NPT top plate port.

Port 3 — Carbonated water outlet (bottom plate): Water exits via a short 1/4" NPT stub on the bottom plate — no internal dip tube. Vertical orientation puts the densest, coldest, most carbonated water at the bottom by default, so the bottom port draws the right water without an internal feature. Outlet runs through 1/4" tubing up to the Westbrass Touch-Flo faucet under CO2 pressure.

Port 4 — Pressure relief valve (top plate, dedicated, 100 PSI set pressure, 40 SCFM relief capacity, Control Devices SV-100 B0D361X97X — industrial pneumatic safety valve, brass body, fit-for-purpose for D2C Founder Edition). Not ASME UV-stamped; not required because this project is not pursuing UL/ETL listing (see `regulatory.md`). The PRV must have its own dedicated port with an unobstructed path to the vessel interior at all times. It cannot share a port via a tee — a blockage, fitting failure, or maintenance disconnect on a shared line could compromise the safety relief path.

The tank interior is passivated with citric acid (one-time, 30–60 min soak of ~4% food-grade citric acid solution in a disposable plastic tub, then thorough water rinse) after welding and before first service. Passivation restores the chromium oxide layer at the weld zones, which is what makes 316L SS (and 304) resistant to pitting corrosion from carbonic acid (carbonated water, pH ~3.5–4). This is the same treatment commercial brewery bright tanks and commercial carbonators receive. A food-safe epoxy coating was considered but rejected: commercial carbonators (Lillium, Brio, SodaStream commercial) all run bare passivated 304/316 SS for decades, and epoxy coatings can fail at pinholes and concentrate corrosion where a uniform oxide layer would spread it harmlessly.

CO2 supply is a standard regulated bottle, set to 70 PSI minimum (typically 70–80 PSI), feeding through the CO2 port via the internal sparge architecture above.

Water is pushed into the tank against CO2 back-pressure by the SEAFLO 22-Series 100 PSI diaphragm pump (B0166UBJX4). Full water path: tap → ASSE 1022 carbonated-beverage backflow preventer (Multiplex 19-0897, lead-free brass body with SS internals, dual check with atmospheric vent, 10–200 PSI, 3/8" MPT × 3/8" MFL with 1/4" barb vent) → 3/8" flare × 1/4" FNPT adapter → SeaFlo pump (3/8" hose barbs) → MAACFLOW 3/8" barb × 1/4" NPT SS adapter → external PTFE-soft-seat check valve (GASHER B0FV2D2FFX, 1/4" NPT SS, PTFE disc on metal poppet confirmed by inspection 2026-04-25; not the pump's internal elastomer check) → 1/4" NPT top-plate water-inlet port. The pump's own integrated checks are a redundant layer #3, not the primary seal, because elastomer checks creep under sustained CO2 back-pressure and gas molecules migrate through elastomer seals that would hold liquid indefinitely. PTFE-on-metal is the standard soft-seat construction in commercial beverage/brewery/food-process check valves at this pressure class — chemically inert to carbonic acid and CO2, no gas-permeation problem, suitable for long-term field service. The CO2-side line carries an identical GASHER 1/4" NPT SS check valve installed inline between the DERPIPE 5/16"-tube × 1/4"-NPT push-to-connect and the LTWFITTING bottom-plate barb adapter — same 2-pack as the water-side check, one valve per side per vessel. This prevents water from back-flowing through the sparge stone, up the silicone tube, and into the CO2 regulator if pressures invert under fault.

ASSE 1022 (not 1024) is the correct standard for this application. 1022 is specifically "Backflow Preventer for Beverage Dispensing Equipment" — required because dissolved CO2 makes carbonic acid at pH ~3.5, which leaches lead from solder joints in household plumbing if it backfeeds. The Multiplex unit's atmospheric vent barb must be routed to an observable drip location (not plumbed into a drain), because the vent is the mechanical telltale: if check #1 leaks, the escaping water/CO2 becomes visible at the vent before anything backfeeds past check #2. The 3/8" MFL outlet connects to downstream 1/4" NPT plumbing via a 3/8" flare × 1/4" FNPT adapter (Hooshing B0BNHVV6HT).

**Level sensing — external reed + internal magnetic float on welded SS rod.** A 1/8" 316L SS rod (Tandefio B0CY4DWJFQ, cut from 12" stock to ~6") is laser-welded vertically to the inside face of the bottom plate, with its top end captured by a small register on the inside face of the top plate. A magnetic donut float (harvested from a DEVMO MINI float switch B07T18PGJ4) slides freely along the rod with the water level. External reed switches (Gebildet B0CW9418F6) are mounted on the outside of the 0.065" 316L SS tube wall (316L is austenitic and non-magnetic — the magnetic field passes through the wall). Two reeds — one at the low-level refill threshold, one at the high-level full threshold. Zero electrical penetrations of the pressure vessel; nothing wetted is anything other than 316/316L SS or food-grade silicone.

Refill is triggered when the faucet is closed and the low-level reed reads empty — never during an active dispense. This is a hard firmware interlock, not a soft preference: introducing 18 °C tap water during a pour raises the dispensed water temperature rapidly (2 °C → ~6 °C after one 12 oz pour under perfect-mix). The tank functions as a thermal reservoir, not a real-time buffer: dispense until the low-level threshold, close the faucet, then the pump refills and the evaporator pulls the new water down to service temperature before the next pour is allowed.

Carbonated water at ~2 °C and pH ~3.5–4 naturally suppresses biofilm and scale formation in the vessel — no scheduled clean cycle is required for the carbonator (the clean cycle in `flavor-subsystem` is for the flavor lines, not the carbonator).

Dispensing is a faucet lever. The carbonated water is already cold, carbonated, and under CO2 pressure — opening the valve sends it directly to the nozzle.

**Refrigeration subsystem**

Compressor, condenser + fan, capillary tube, and filter drier are harvested from a countertop ice maker. The evaporator cold plate is discarded and replaced with a custom-wound copper coil around the carbonator tank. Two ice makers purchased for teardown:

- Frigidaire EFIC117-SS (26lb/day) — ASIN B07PCZKG94, $78.70
- Generic countertop (8 cubes/6min, 26lb/day) — ASIN B0F42MT8JX, $63.80

Evaporator coil: GOORY 1/4" OD x 0.187" ID, C12200 ACR (ASTM B280), thick-wall (0.031") — ASIN B0DKSW5VL9. The 0.031" wall resists thinning at bends around the carbonator tank. For production runs, the same product ships in 50 ft rolls (largest thick-wall size on Prime). BELLA BAYS (ASIN B0BXKK62XL) is an equivalent alternative at the same spec.

Compressor cycling is controlled by firmware, not a mechanical thermostat. Two DS18B20 waterproof 1-wire temperature probes on a shared bus: one clamped to the carbonator tank wall reads water-side temperature for cycle control (target ~2 °C, hysteresis ~2 °C — compressor off at 2 °C, on at 4 °C); a second bonded to the evaporator suction line reads coil temperature for freeze protection (hard cutout at −8 °C to prevent the water in the tank from freezing against the coil). The ESP32 reads both probes and drives the Teyleten relay module on GPIO 14 to switch the compressor's AC hot leg. A minimum off-time enforced in firmware (~3 min) prevents short-cycling and protects the compressor's start capacitor.

Factory charge is R-600a (isobutane) — R-600a is carved out of the EPA Section 608 venting prohibition as a natural refrigerant, so the loop is vented to atmosphere through a piercing valve rather than recovered into a machine. No 608 certification is legally required. Teardown sequence: vent factory charge, cut out old drier and braze in a replacement (Supco D111, integrated Schrader), pull vacuum, recharge from a 6 oz Enviro-Safe pure R-600a can (~40 g per system, metered by mass). Total component cost per unit: ~$100-110.

Fallback: the RIGID DV1910E (~$600 + 20-30% import tax) is a factory-sealed, pre-charged OEM module with a flexible copper coil evaporator that can be reshaped without breaking the refrigerant loop. The cost premium buys a UL/ETL listing for retail channels (Amazon, big-box) that require one.

**Cold core assembly (inside out)**

Layer 1: Custom-fabricated 316L SS carbonator vessel, vertical orientation. Plan A: 5" OD × ~6" tall round tube + 1/4" plates. Plan B: racetrack 5.566" × 3.966" × 6.000" (304 SS, fallback inventory). The vessel is always vertical regardless of cross-section.

Layer 2: Copper evaporator coil wrapped tight around the tank, bonded to the tank OD with 3M 425 aluminum foil tape (thermally conductive, replaces the earlier "thermal compound" plan which didn't suit the macro-scale gap geometry without clamping pressure).

Layer 3: 3D-printed inner shell with ~1/4" gap, filled with two-part closed-cell pour-in-place polyurethane foam (2 lb density, ~R-6/in). Pour-in-place is preferred over spray for this closed annular geometry — two components mix 1:1, get poured through a fill port at the top of the shell, and rise to fill the cavity without overspray. Vent holes in the shell allow excess foam to escape during cure; trimmed flush after hardening.

Layer 4: Flavor reservoirs wrapped around the insulated core, serving as both syrup storage and thermal mass. Flavor-reservoir Plan A is the known-good prototype path: two 3D-printed arch-shaped cradles, each holding a 1L Platypus bladder. Each bladder cap is drilled and fitted with a John Guest bulkhead fitting connecting to 1/4" hard RO tubing that runs to the peristaltic pumps. The bladders are permanent internal plumbing — filled from a user-accessible hopper via the pumps, cleaned in place by a software-controlled rinse cycle (water in, water out to nozzle, air in, air out to nozzle, repeat).

Flavor-reservoir Plan B is a pair of custom printed hard reservoirs, one per flavor, conforming directly to the cold-core envelope instead of forcing off-the-shelf bottle geometry into the under-sink package. The reservoirs are vented, not service-pressure vessels: 1L usable volume target, low outlet sump, high filtered vent, fill/dispense/clean paths through the same valve manifold. For Plan B the reservoirs remain separate printed parts that fit inside the foam-bag shell; an integrated reservoir/shell print is a later Plan C idea. Today's foam-bag-shell pockets are just under 1L internal volume, so the expected package change is a small X-axis pocket enlargement without disturbing the Y/Z pressure-vessel and plumbing envelope. The test plan and candidate food-contact PET-family filaments live in `printed-parts/plan-b/reservoir/README.md`. Plan B only replaces the bladder/cradle physical package; the user experience and manifold behavior stay the same.

Layer 5: 3D-printed outer shell with ~1/2" to 3/4" gap, filled with the same pour-in-place foam, same process as inner layer.

Total cold core dimensions: TBD after spray foam and shell layers are added around the 5" OD × ~6" tall vessel core.

The flavor reservoirs passively pre-chill to roughly 8-15°C by sitting in the thermal gradient between the near-freezing inner core and ambient air. The inner foam layer prevents either reservoir architecture from freezing against the evaporator.

**Flavor subsystem**

Two peristaltic pumps (food-grade silicone tube inside the pump head; 1/4" LLDPE hard tubing for the line runs in and out), mounted in the replaceable pump cartridge assembly. The cartridge uses John Guest quick-connects and a palm-squeeze release plate for tool-free swap. The pumps pull flavor from the internal flavor reservoirs (Platypus bladders in Plan A, printed hard reservoirs in Plan B) and inject it at the dispense nozzle alongside the carbonated water.

Pump direction is forward-only. Filling, dispensing, and clean-cycle operations are selected by the valve manifold, not by reversing the pump. The canonical valve-state truth table is `topology/fluid-topology.md`: hopper/BiB/tap-water inputs are routed to the pump inlet through source-selection valves, and the pump outlet is routed either back to the selected bag or out to the nozzle.

Each flavor has two input paths to the reservoir. The primary path is the shared hopper funnel on the user-facing side for pouring from SodaStream concentrate bottles, with a solenoid-selected route to the appropriate internal flavor reservoir. The funnel has a removable dishwasher-safe silicone cover. The secondary path is a bag-in-box adapter on the rear of the enclosure — a barb or quick-connect fitting that connects to a standard BiB line. Both paths feed through the pump into the same internal refrigerated reservoir. The BiB adapter is present but not prominently marketed; it serves customers who source their own commercial syrup.

**Enclosure layout**

The enclosure is an under-counter appliance, installed inside the kitchen cabinet beneath the sink. Its front face points toward the kitchen cabinet door; its back sits near the kitchen cabinet's rear wall. All rear-face connections (water inlet, CO2 line, AC inlet, BiB adapter) assume the typical 2–4" working gap between the appliance back and the cabinet rear wall, consistent with under-sink plumbing convention. Front-to-back the internal layout runs: condenser + fan at the front, compressor in the middle-bottom just behind the condenser, valve manifold + 100 PSI diaphragm pump + Kamoer peristaltic pump cartridges stacked above the compressor in the middle, and the cold core occupying the full rear of the enclosure against the back wall.

Thermal zones separate cleanly. Hot side at the front: the condenser vents forward through a grille on the lower front face of the enclosure, drawing cool intake from the kitchen cabinet's toe-kick gap. Cold side at the back: the carbonator, flavor reservoirs, and chilled dispense line, insulated by the cold core's inner and outer foam shells. The compressor bridges the two, positioned for short refrigerant lines to the front-mounted condenser; the longer suction run back to the evaporator coil around the carbonator is not efficiency-critical.

Placing the cold core at the back shortens the chilled dispense run to a minimum. The faucet penetration in the countertop is typically at the back edge (where the sink meets the backsplash), so the carbonated water line runs straight up from the cold core through a short insulated tube — minimizing heat pickup on the most temperature-critical path in the system.

**Backflow vent monitoring**

The Multiplex 19-0897's atmospheric vent terminates inside the kitchen cabinet over a small internal drip pan, not routed up through the counter. A moisture sensor in the pan ties to an ESP32 input — when the vent weeps (the mechanical telltale that check #1 has begun to leak), firmware fires an audible alarm at the device and an iOS app notification. This trades the always-visible drip of a countertop tray for a one-time-loud, persistent-software-flagged alert; in exchange the customer keeps a clean countertop with no extra penetrations.

**User-facing elements, by location**

*Above counter, through-counter fixtures over the sink:* faucet lever, KRAUS air switch for flavor select, RP2040 round display showing the active flavor's logo.

*Enclosure top, front half* (reached by the user opening their kitchen cabinet door — the enclosure itself has no hinged doors, its top is an integral funnel): flavor hopper, a large funnel covering most of the front half of the top face, sized to accept a pour from a SodaStream concentrate bottle without splash, feeding through solenoid-selected valves down to the appropriate internal flavor reservoir.

*Enclosure front face, middle:* pump cartridge access door (this one is on the enclosure itself) for swapping the Kamoer peristaltic pump when its silicone tubing wears out.

*Enclosure front face, lower:* condenser exhaust grille.

**Power**

The appliance is cord-and-plug 120 VAC through the rear C14 inlet. The harvested ice-maker compressor and condenser fan remain 120 VAC loads, switched on the AC hot leg by a firmware-controlled relay. The Mean Well 12 V supply creates the low-voltage bus for the diaphragm pump, peristaltic pumps, solenoid valves, motor driver, valve drivers, controllers, displays, and sensors. Current power topology lives in `wiring/power.mmd`.

**Rear-panel AC inlet**

The AC inlet is an IEC 60320 C14 panel-mount receptacle (MXR B07DCXKNXQ) accepting a standard NEMA 5-15P → C13 line cord. When the outer enclosure rear panel is printed, the C14 inlet is **recessed 3–5 mm into the panel face** with a printed shroud around the inlet perimeter. On insertion, the cord housing nests into the recess and ends flush with the rear panel surface, visually masking the IEC-mandated gap between cord and inlet bezel.

This is purely a fit-and-feel improvement; no electrical or mechanical change to the connector itself. The visible gap between cord housing and inlet face is by design under IEC 60320, which specifies only the male-blade insertion region — not face-to-face mating distance. The C13/C14 cross-test pair (uxcell inlet B07PXSLBF4 + Tripp Lite cord B0000511C0, ordered Apr 24, 2026) confirmed all four parts in the MXR × Monoprice / MXR × TrippLite / uxcell × Monoprice / uxcell × TrippLite matrix mate to spec — the gap is the standard, not the parts. For a hand-built Founder Edition appliance the printed shroud is the cheapest path to a "fully seated" user-facing appearance.

Locking C13 cords (Tripp Lite P-Lock series and similar) were considered and rejected: the design concern is fit/feel feedback at insertion, not mechanical retention, and friction-only retention is sufficient for an under-counter install. A hardwired-cord alternative (KitchenAid / Vitamix pattern, no detachable connector at all) is held under separate consideration and would obviate the bezel-recess solution if pursued.

**Rear-panel nameplate**

A separately-printed serialized plaque mounted on the rear face of the enclosure. Carries regulatory markings (model, serial, 120V 60Hz input rating), the Founder Edition number and signature, and a per-unit QR code linking to `homesodamachine.com/u/NNN`. Printed separately from the enclosure so its fine text and QR can use nameplate-grade print settings without forcing them onto the bulk of the cabinet. Full spec in [`printed-parts/nameplate/README.md`](printed-parts/nameplate/README.md).

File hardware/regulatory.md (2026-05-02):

# Regulatory Posture

Consolidates the regulatory conclusions already reached across prior conversations so they do not need to be re-derived. Primary path is direct-to-consumer sale via homesodamachine.com. Secondary path is big-box retail (Amazon, Walmart, etc.) via the RIGID DV1910E listed-module fallback.

## Sales channels

| Channel | UL / ETL listing | Notes |
|---|---|---|
| Direct-to-consumer (homesodamachine.com) | Not required | Listing is a retailer/insurer requirement, not federal law. |
| Big-box retail (Amazon, Walmart, Home Depot, etc.) | Required | Use RIGID DV1910E listed-module fallback. See `hardware/future.md`. |

## EPA Section 608 — refrigerant handling

R-600a (isobutane) is carved out of the Section 608 venting prohibition as a natural refrigerant. No technician certification is legally required to vent, cut, braze, evacuate, or recharge the harvested refrigerant loop on this project.

Primary citation: `hardware/harvested/ice-maker/README.md` (the line stating the 608 exemption).

Does not apply to: a pivot to an R-134a or other HFC donor. In that case 608 Type I certification applies (open-book online, ~$25, 84% pass).

## EPA SNAP — refrigerant end-use approval

SNAP (Significant New Alternatives Policy, Clean Air Act §612) approves refrigerants for specific product categories. Natural refrigerants are not blanket-exempt from SNAP — approval is granted per end-use.

R-600a is SNAP-approved for this project's end-use category (self-contained commercial refrigeration, which covers countertop refrigerated beverage dispensers). This project's charge (30–50 g) is well under applicable SNAP charge limits.

Approval conditions this project must satisfy at the product level (no third-party listing needed):

- Design per UL 60335-2-89 (hydrocarbon charge handling, enclosure) — compliance, not listing
- Flame symbol (ISO 7010 W021) marking on the unit
- "Flammable refrigerant" text marking on the unit
- Installation / service instructions note the refrigerant and charge mass

## UL 60335-2-89 — hydrocarbon appliance safety

Charge cap for this equipment class is 150 g. Factory donor charge is 30–50 g per unit — well below the limit.

Primary citation: `hardware/harvested/ice-maker/README.md` (the line stating charge is "well under the 150 g UL 60335-2-89 limit").

This standard governs design compliance regardless of whether a UL listing is pursued. D2C sale does not require the listing but the design should still conform.

## CPSC general safety duty

Federal Consumer Product Safety Commission applies to any consumer product sold in the US. Product must not be unreasonably dangerous. No listing or certification required — this is a general duty of care, independently honored by the project's design practice.

## AIM Act — not applicable

The American Innovation and Manufacturing Act regulates HFCs. R-600a is a hydrocarbon, not an HFC, and is outside the scope of AIM Act phase-down rules, leak-management thresholds (15 lb rule, Jan 2026), and refillable-cylinder requirements.

Applies only if the project pivots to an HFC refrigerant.

## Assembly-time safety — argon purge during brazing

Not a regulation, but load-bearing for Path A execution.

After the factory R-600a charge is vented, residual hydrocarbon remains dissolved in the compressor oil and pooled in low points of the tubing. When a torch is applied to copper near an oil-soaked compressor pocket, the flame front pulls residual hydrocarbon into itself. Mitigation is to flow low-pressure argon (a few psi, flowing — not static) through the opened loop during and through the braze, sweeping residual fuel out ahead of the heat.

The documented build path reuses the argon cylinder already present for laser welding, with the appropriate purge-side regulator / tubing setup for refrigeration brazing.

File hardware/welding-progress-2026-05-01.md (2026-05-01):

# Welding progress — Snapshot 2026-05-01

**This is a point-in-time snapshot, not a living document.** Captures the state of laser-welding practice on the X1 Pro after roughly a week of off-and-on practice, on the eve of the second "realistic test fixture" attempt and the start of the 316L production-stock work. Recipe and rationale recorded here for posterity and to feed forward into future conversations. Will go stale; treat as a reference point, not the canonical practice log.

## TL;DR — recipe to try on the second test fixture

What I've been doing today: 75% power, 80Hz frequency, 2mm wobble width, 10 mm/s wire feed, 2s argon pre-/post-flow, ER308L .030 wire, no rise-up / no fall-down configured, no plate prep, no inside argon purge. Got the first test fixture leak-free after 3 weld + water-test iterations.

What I plan to do next, on my last "realistic" test piece:

> Power: 60%
> Wobble width: 2mm, frequency: 80Hz, pattern: circle if available
> Wire feed: 12 mm/s
> Rise-up: 50ms / Fall-Down: 100ms
> Argon: 2s pre, 2s post (unchanged)
> Plate prep: 30s with 120 grit on the cut edge

Then leak-test it like the previous one and iterate.

After that, the plan is to move to 316L stock (vessel tube + endcap plates already in hand) and transition from water testing to air pressure testing once the NPT tapping is figured out. Tapping supplies arrive Saturday 2026-05-02.

## Where this stands now

- Two "realistic test fixtures" purchased before the 316L pricing turned out reasonable: 1/16"-wall (~0.065") × 5" OD 304L tube + 1/4"-thick 304L endcap plates that slip-fit inside the tube ends. ~$80 per fixture, two total. Same wall thickness, same plate thickness, same joint geometry as the 316L production design — only the alloy differs. ER308L .030 wire on these for now; ER316L .030 (STARTECHWELD spool, ACQUIRED 2026-04-27) ready for the 316L production parts.
- **First fixture (today's session):** leak-free after three weld + water-test iterations. Initial weld leaked at many points across both endcaps; second pass closed most leaks down to three; third pass on those three spots closed it. Visible warping on the 1/16" tube wall, less than what was seen on flatter scrap with more heat input — judged acceptable. Retained as a proof artifact.
- **Tack pattern in use:** 8 tacks, picking opposite sides and bisecting (12, 6, 3, 9, then 1.5, 7.5, 4.5, 10.5 o'clock), then bead segments at ~1/8 of circumference each, with minimal overlap into the tacks. This works — do not change.
- **Two issues observed today:**
  1. Wire stuck to the bead 3–4 times across the session, more frequently early and less frequently late as motion got more consistent. The trail-off-as-trigger-releases motion technique was discovered organically and helped.
  2. Thin-wall warping on the 0.065" tube. The C110 copper bar (YTKavq 1/4" × 2" × 12") was used as a chill block but only contacts the curved tube along a tangent line, limiting heat extraction.

## Provenance of the recipe — where these changes came from

The headline recipe above is **not validated personal practice — it is externally-sourced advice that has not yet been tried on the welder.** It came out of a Claude Code conversation on 2026-04-30 / 2026-05-01 between the user and Claude (Opus 4.7). The user described the two issues from today's session (wire sticking, thin-wall warping) and the parameters in use (75% / 80 Hz / 2 mm / 10 mm/s wire feed / 0 ms rise-up / 0 ms fall-down / no plate prep / no inside argon purge). Claude spawned a research agent to pull the X1 Pro manual and parameter pages from XLaserlab's site and to gather published SS-welding recipes from comparable 700 W-class welders. The recipe is the synthesis. The user had not previously consulted the X1 Pro manual's parameter pages and was not aware of several of the parameters (notably Rise-up Time and Fall-Down Time) before this conversation. The next session is the first hands-on test of this recipe.

The plain-English version: I asked Claude for help. Claude had an agent dig up the manual. The recipe is what came back. I haven't tried it yet.

## Context behind each recipe change

### Wire sticking — Fall-Down Time is the high-leverage fix

The X1 Pro exposes **Rise-up Time** (0–1000 ms, soft start) and **Fall-Down Time** (0–1000 ms, soft stop) on the laser power. The user had both at 0 — not a deliberate choice, just unfamiliarity with the parameters. The agent's manual research surfaced them as the published wire-stick remedy. With both at 0, the laser dies instantly while wire is still in the puddle, and the puddle freezes around the wire. Setting Fall-Down to ~100 ms makes laser power decay smoothly so the puddle cools gradually with the wire in it instead of freezing instantly. Per XLaserlab's published wire-stick remedy, this plus correct feed speed is the official path. **The X1 Pro does not have a wire-retract parameter** — Fall-Down is the substitute.

The trail-off motion the user discovered organically during the session — continuing to pull around the curve and away as the trigger releases — is the manual-technique equivalent of Fall-Down Time. The two compound; keep doing the motion even with Fall-Down configured.

### Power 75% → 60%, wire feed 10 → 12 mm/s

The user had been running 75% on feel, adjusted by experimentation across scrap and judged by visible color on the back side of the test pieces. The agent's research surfaced two facts:

1. The X1 Pro is officially **700 W**, not 800 W. XLaserlab catalog, manual download center, and multiple reviewers all agree on 700 W. The project's [marketing/video/first-weld.md](../marketing/video/first-weld.md) records 800 W — worth confirming on the HMI splash on the unit, but the public spec is 700 W.
2. Published recipes (STRION, GWEIKE) for 1.5–2 mm 304 SS on 700 W-class heads converge on **50–70% power**. 0.065" wall = 1.65 mm sits right at the thin end of that range, so the user's 75% is on the hot side relative to the published ranges.

Lower power = lower peak heat into the thin tube wall = less warping. The slight wire-feed bump (10 → 12 mm/s) compensates so total fill per inch of bead stays roughly the same and the comfortable travel-speed range is preserved.

### Wobble pattern — try circle / "O" if menu has it

The user had not explored the X1 Pro's wobble-pattern menu beyond whatever default is in use. XLaserlab does not publicly enumerate the X1 Pro's pattern shapes, but most welders in this OEM tier offer line / circle / figure-8 / zigzag. The conversation surfaced "try circle for fillet welds" as a try-it-and-see lever — circular wobble agitates the puddle uniformly across both sides of the joint and is more forgiving of slight gun-angle drift than line/zigzag. If the menu doesn't have "circle," current pattern is fine.

### Wobble frequency at 80 Hz — the user's observation was correct

The user observed during practice that varying frequency only changed the visible bead pattern, with no apparent effect on heat or penetration. The agent's manual research confirmed this: the 1–100 Hz parameter on the X1 Pro is the galvo wobble rate, not laser pulsing. Pulse-light is a separately selectable mode with its own duty cycle. The observation was correct. Leave frequency at 80 Hz.

### Plate prep — sand the SendCutSend cut edge

The user did no plate prep on today's first fixture — the SendCutSend cut edges went into the joint as-cut. Claude flagged this in the conversation as a likely contributor to wire stick. The SendCutSend laser-cut endcaps carry a recast layer (high-melting oxide + nitride from the N2 cutting gas) on the OD edge, and that edge ends up directly under the weld bead. Unprepped, it causes erratic puddle behavior and contributes to wire stick when the puddle skips over a hot oxide spot. 30 seconds with 80–120 grit on each plate's OD before fitting is standard practice and should be done on every plate, production-side too.

### Inside argon — skip for this stage

The user did not back-purge the inside of the tube during today's session and observed yellow / light brown coloration on the inside (no black scale). Asked in the conversation whether this was acceptable. Confirmed: yellow/brown is chromium oxide under partial protection from the gun's argon migrating through the slip-fit gap between plate and tube ID, and it dissolves cleanly in the post-weld citric-acid passivation soak that's already part of the production flow ([future.md](future.md) carbonation subsystem). Black scale would not dissolve cleanly — that's the line. Yellow/brown is fine for this stage; skip the inside purge.

## What's working — don't change

- Tack pattern: 8 tacks, opposite-side bisecting.
- Bead segment scale: ~1/8 of circumference per bead, minimal overlap into the tacks.
- Trail-off motion: keep doing this even with Fall-Down Time configured — they compound.
- Argon pre/post-flow at 2 s / 2 s: within recommended range.
- Wire feed rate floor: 10 mm/s was already at the lower bound of comfortable; the 12 mm/s recipe nudges up but doesn't push the floor down.

## Open questions / things to watch

1. **700 W vs 800 W on the unit splash.** Doesn't change the recipe (% is %), but matters for any absolute-wattage comparison.
2. **Wobble pattern menu contents.** Confirm whether "circle" is selectable; if not, current pattern is fine.
3. **Internal copper plug.** Suggested by Claude in the conversation as the highest-leverage warp-reduction lever besides power reduction. Cut a ~2" length from the YTKavq C110 1/4" × 2" × 12" bar and drop it inside the tube against the inside face of the plate before welding. Heat dumps through the plate into the copper, away from the thin tube wall. Not part of the headline recipe (the user did not include it in the parameters they planned to take to the next session) but worth trying alongside it on the second fixture.
4. **Travel speed.** Not separately tracked — only "wire feed" speed appears in the parameter set as the user has been using it. If the 60% / 12 mm/s combination feels different in practice, travel speed may need to come down to match the lower power. Iterate.
5. **If wire stick persists after Fall-Down = 100 ms:** check feed-roller tension, contact-tip wear, and wire stickout distance (5–10 mm past the contact tube is the standard window — too short and the wire heats backwards into the tip).

## Equipment + consumables, current state

- **Welder:** XLaserlab X1 Pro 3-in-1 laser welder/cleaner/cutter, ACQUIRED 2026-04-13, single wire feeder included.
- **Filler wire (304L practice):** ER308L .030 across multiple spools, sufficient.
- **Filler wire (316L production):** STARTECHWELD ER316L .030 10-lb spool (B09BKFBXT9), ACQUIRED 2026-04-27.
- **Heat sink:** YTKavq 1/4" × 2" × 12" C110 pure copper flat bar (B0DR2PX6TT), ACQUIRED 2026-04-24 — available for both external chill-bar and internal heat-sink-plug use.
- **Argon:** existing cylinder feeding the welder via RX Weld regulator. Same cylinder is the source for the brazing-purge rig planned for the refrigeration loop.
- **Practice coupons:** 304 SS 4"×6"×1/16" sheets (3-pack ACQUIRED) and 4"×4"×0.04" sheets (ACQUIRED). Used through the past week's flat-coupon practice.
- **Realistic test fixtures:** two pieces total. One consumed today (leak-free, retained as proof). One remaining for the next-session attempt of this recipe.
- **316L production stock (in hand for after the next test):** OnlineMetals #12498 — 5" OD × 0.065" wall 316 welded SS round tube, qty 10, MTRs in hand. SendCutSend 1/4" 316 SS endcap plates with 2-hole pilot pattern (`endcap-circular-2hole.dxf`), qty 20.
- **Tapping supplies:** Amazon order 112-2348373-7907448 ($264.96 delivered) — WEN drill press, Drill America 1/4"-18 NPT tap + tap wrench, Brown & Sharpe tap guide, plus wood-fixture material — arriving Saturday 2026-05-02. After tapping is figured out, the test cycle moves from water testing to air pressure testing.

## What this snapshot is NOT

- Not a living practice log — re-run as a fresh dated snapshot when there's another inflection point worth capturing.
- Not a production-parameter prescription — production parameters will be derived from the next-session 60% recipe outcome plus the 316L transition.
- Not a substitute for hands-on observation — the trail-off motion, the puddle behavior, and the right power for a given joint geometry are felt, not read from a doc.

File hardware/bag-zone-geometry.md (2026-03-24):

# Bag Zone Geometry — 1L Incline-Mounted Bags in the 400mm Enclosure

> **DECISION (2026-03-24):** Enclosure height is locked at **400mm**. The device must be shorter than its companion soda water machines (Brio 460mm, Lillium 440mm) since our device is subordinate to theirs. This means **1L Platypus bags** (not 2L). Bags mount at an **18-20 degree incline** with two-point stretch (sealed end high, connector low). Two bags stack vertically within the bag zone.

This document defines the resolved bag zone geometry for the 400mm enclosure, incorporating incline bag mounting, dip tube drainage, drip tray removal, and pump-assisted filling.

---

## 1. 1L Platypus Bag Dimensions

| Parameter | Value |
|---|---|
| Height (when full) | ~250mm |
| Width | ~140mm |
| Thickness (when full) | ~40mm |
| Connector | 28mm threaded cap at one narrow end |
| Sealed end | Heat-sealed seam at opposite narrow end |

The Platypus Drink Tube Kit screws onto the 28mm connector. A dip tube extends from the cap through the bag interior, creating a sealed path. The bag is effectively a sealed vessel with a single port (the dip tube bore, 1/4" ID / 6.35mm).

---

## 2. Vertical Space Budget

The drip tray (previously 15mm) is removed. Analysis of every liquid scenario in the system found no justification for an internal drip tray — the fluid path is fully sealed during operation, there is no condensation source, and the single scenario it would help with (slow connector weep from loose zip ties) is better addressed by using hose clamps and proper assembly. The enclosure floor is a flat 4mm panel.

The "drip shelf" at ~310mm is retained as a structural/organizational shelf (electronics shelf), not a liquid barrier. It provides DIN rail mounting, ties the side walls together, and separates zones for assembly.

| Zone | Bottom (mm) | Top (mm) | Height (mm) | Contents |
|---|---|---|---|---|
| Floor panel | 0 | 4 | 4 | Flat PETG panel |
| Bag zone | 4 | 180 | 176 | Two 1L Platypus bags, incline-mounted at 18-20 deg |
| Dock shelf | 180 | 186 | 6 | 6mm PETG structural shelf |
| Cartridge cavity | 186 | 266 | 80 | Cartridge envelope (150W x 130D x 80H mm) |
| Lever clearance | 266 | 306 | 40 | Cam lever swing above cartridge top |
| Electronics shelf | 306 | 310 | 4 | Open structural shelf with cutouts for wiring and airflow |
| Electronics zone | 310 | 400 | 90 | ESP32, L298N x3, RTC, MCP23017, fuse block, DIN rail |
| **Total** | **0** | **400** | **400** | |

```
    ┌──────────────────────────────────────────────────────┐
    │  ESP32, L298N x3, RTC, DIN rail, fuse block         │ 400mm
    │                                                      │
    │  ═══════════ ELECTRONICS SHELF (310mm) ═══════════   │
    │                                                      │
    │  ┌── CARTRIDGE ──┐  solenoids, tees, needle valve    │
    │  │   dock        │  flow meter                       │
    │  └───────────────┘                                   │
    │  ═══════════ DOCK SHELF (180mm) ═══════════════════  │
    │                       11mm gap                       │
    │                             ──────────────*  BAG 2   │
    │                            /       sealed (169mm)    │
    │                 BAG 2     /   18 deg                  │
    │                          /                           │
    │                    *────*  connector (73mm)           │
    │                   ─ ─ ─ ─  5mm gap                   │
    │                         ──────────────*  BAG 1        │
    │                        /       sealed (126mm)         │
    │             BAG 1     /   18 deg                      │
    │                      /                               │
    │                *────*  connector (30mm)               │
    │  ═══════════ FLOOR PANEL (4mm) ═══════════════════   │ 0mm
    └──────────────────────────────────────────────────────┘
    FRONT                                             BACK
    ◄─────────────────── 250mm depth ──────────────────►
```

---

## 3. Incline Bag Mounting — Geometry

Each bag mounts at an 18-20 degree incline from horizontal, stretched between two fixed points: the connector (low, at the front of the enclosure) and the sealed end (high, at the rear). This replaces vertical hanging, which required 250mm+ of vertical space that is unavailable in the 400mm enclosure.

### 3a. Incline Geometry (18 degrees)

| Parameter | Value |
|---|---|
| Bag length | 250mm |
| Vertical rise (250 x sin 18) | 77mm |
| Horizontal run (250 x cos 18) | 238mm |
| Bag thickness (perpendicular) | ~40mm |
| Vertical projection of thickness (40 x cos 18) | ~38mm |
| Total vertical per bag (rise + thickness) | ~115mm |

The 238mm horizontal run fits within the 242mm interior depth with 4mm margin. The vertical dimensions accommodate two stacked bags within the 176mm bag zone.

### 3b. Why 18-20 Degrees

The angle is bounded by two constraints:

**Upper bound (~30 degrees):** At steeper angles, two stacked bags exceed the 176mm bag zone height. A single bag at 30 degrees fits (rise 125mm + thickness 35mm = 160mm), but two bags do not (the upper bag's sealed end reaches ~210mm, well above the 180mm dock shelf).

**Lower bound (~15 degrees):** At shallower angles, the horizontal run exceeds the 242mm interior depth, and gravity assistance becomes minimal (sin 15 = 0.26).

At 18-20 degrees, two stacked bags fit with 11-17mm of clearance to the dock shelf, and the gravity component along the bag axis is sin(18-20) = 0.31-0.34 — roughly one-third of gravitational force driving liquid toward the connector.

### 3c. Advantages Over Vertical Hanging

| Factor | Vertical Hanging | Incline Mount (18-20 deg) |
|---|---|---|
| Vertical space required | 250mm+ (bag + connector + hook) | ~140mm (rise + thickness + clearance) |
| Fits in 176mm bag zone | No — requires top folding or 500mm enclosure | Yes — designed for the space |
| Drainage reliability | Good (full gravity) | Good (partial gravity + pump suction) |
| Last 10-20% behavior | Bag becomes floppy, random collapse, potential kinking | Liquid pools at connector end, collapse is top-down along incline |
| Collapse control | Uncontrolled random folding | Two-point tension constrains collapse to thinning-in-place |
| Dip tube interaction | Tube hangs straight down, parallel to gravity | Tube extends UP along incline, reaches into liquid pool, last to see air |

---

## 4. Two-Bag Arrangement — Vertical Stacking

Two 1L bags are stacked vertically, both inclined in the same direction (connector at front-low, sealed end at rear-high). Each bag consumes the full interior depth (238mm of 242mm) and the full interior width (140mm of 272mm, centered with 66mm per side for tubing).

### 4a. Vertical Position of Each Bag (at 18 degrees)

| Parameter | Bag 1 (Lower) | Bag 2 (Upper) |
|---|---|---|
| Connector center height | 30mm | 73mm |
| Connector top edge | 49mm | 92mm |
| Sealed end center height | 107mm | 150mm |
| Sealed end top edge | 126mm | 169mm |

Gap between Bag 1 top and Bag 2 bottom at the connector end: 73 - 49 = 24mm (comfortable). At the sealed end, Bag 2 top reaches 169mm, leaving 11mm clearance to the 180mm dock shelf.

### 4b. Side Cross-Section

```
    ═══════════════ DOCK SHELF (180mm) ═══════════════
                                          ·  ← 11mm clearance
                                        * BAG 2 sealed (169mm top)
                                       /
                            BAG 2     /    18 deg
                                     /
                            * conn. /
                           (92mm)  * ← BAG 2 connector (73mm center)
                   ─ ─ ─ ─ ─ ─ ─ ─ ─  5mm gap
                          * BAG 1 sealed (126mm top)
                         /
              BAG 1     /    18 deg
                       /
              * conn. /
             (49mm)  * ← BAG 1 connector (30mm center)

    ═══════════════ FLOOR PANEL (4mm) ═══════════════
    FRONT                                        BACK
    ◄────────────── 238mm run ──────────────────►
```

### 4c. Top View

```
    ┌────────────────── 272mm interior ──────────────────┐
    │                                                     │
    │      ┌──────────────────────────────────────┐      │
    │      │                                      │      │
    │      │  BAG 1 and BAG 2 (same footprint)    │      │
    │      │  140mm wide, 238mm deep              │      │
    │      │  stacked vertically, not in depth    │      │
    │      │                                      │      │
    │      └──────────────────────────────────────┘      │
    │                                                     │
    │  ◄──── 66mm ────►◄── 140mm bag ──►◄── 66mm ────►   │
    │   tubing space          width        tubing space   │
    │                                                     │
    │  FRONT                                     BACK     │
    │  ◄──────────────── 242mm depth ──────────────────►  │
    └─────────────────────────────────────────────────────┘
```

Both bags share the same depth footprint (238mm). The 66mm clearance on each side of the bag provides space for tubing routing along the enclosure walls.

---

## 5. Drainage and the Dip Tube

The Platypus Drink Tube Kit creates a sealed path into the bag. The dip tube extends from the connector (low point) upward along the incline toward the sealed end, reaching into the liquid pool inside the bag.

### 5a. Dip Tube Orientation on Incline

```
                                  sealed end (high)
                                 /
                                /
                               /   bag interior
                              /
                   ┌─────────/─── dip tube extends UP
                   │        /     along the incline toward
                   │       /      the sealed end
                   │      /
      cap ─────────┤     /
      connector    │    /
                   └───/
                      /
    ═══ FLOOR PANEL ═══
```

The tube opening sits partway up the incline, in the middle of the liquid volume. As the bag drains, liquid slides downhill to the connector, but the tube opening remains submerged until the bag is nearly empty (last 5-10%).

### 5b. Drainage Efficiency

The inclined dip tube configuration achieves near-complete bag evacuation:

1. Gravity pulls liquid toward the connector (low point) at sin(18-20) = 0.31-0.34 of full gravitational force
2. The bag collapses from the sealed end (high) downward — the empty portion has no liquid behind it
3. The dip tube opening is the last point to be exposed to air, providing a natural buffer
4. At ~20% remaining (~200ml), liquid concentrates in a wedge at the connector end, roughly 80-100mm long x 140mm wide x 15-20mm thick

The dip tube adds ~11ml of dead volume (7.9ml inside bag + 3.2ml external), which is insignificant relative to 1L capacity (1-2%). This dead volume must be flushed during clean cycles.

### 5c. Kinking Analysis

On a stretched incline mount, kinking is largely a non-issue:

- **Kinks above the liquid line are irrelevant** — the collapsed upper bag is empty, nothing is trapped
- **Kinks below the liquid line are self-healing** — liquid weight on the uphill side pushes through folds as the pump draws from below
- **The stretched mount prevents severe kinking** — mild tension along the bag's length axis resists lateral folding; the bag thins in place rather than folding randomly

This effectively resolves the collapse/kinking concern from prior research without requiring elastic frames, rollers, or squeeze mechanisms.

### 5d. Flow Restriction

The dip tube (1/4" ID, 6.35mm) is NOT the flow bottleneck. The black silicone tubing (1/8" ID, 3.175mm) has 4x less cross-sectional area. The dip tube contributes less than 4% of total flow resistance (Poiseuille analysis). The Kamoer pump's suction easily overcomes the hydrostatic head in the dip tube (~0.37 PSI for a 250mm column).

---

## 6. Filling — Pump-Assisted via Reversed Pump

Bags are filled using the existing Kamoer peristaltic pump running in reverse. The hopper connects downstream of the pump (at a TEE between pump outlet and dispensing point). During refill, the pump reverses direction: pulling concentrate from the hopper and pushing it through the dispensing solenoid, through the bag-side tee, through the dip tube, and into the bag.

This approach was validated by the pump-assisted filling research, which corrected a prior misconception that the bag was an "open pouch" — the dip tube creates a sealed path, and bidirectional flow through it is already proven by existing priming and clean cycle operations.

### 6a. Refill Flow Path

```
Hopper → [hopper valve OPEN] → TEE2 → [pump REVERSED] → [disp solenoid OPEN] → TEE1 → dip tube → Bag
```

A check valve at the dispensing point prevents air from being pulled in during refill. The hopper should be sealable (silicone cap with duckbill valve for air inlet) to minimize air exchange with the bag contents.

### 6b. Hardware Additions

| Item | Qty | Est. Price |
|---|-----|---|
| 1/4" inline check valve (push-connect) | 2 | $6-10 |
| TEE fitting (pump outlet side) | 2 | $0 (already in hand) |
| Hopper solenoid valve (Beduan 12V NC) | 2 | $18 |

No additional pumps, drivers, or GPIO pins needed. Pump reversal is a 3-line firmware change (swap H-bridge inputs via L298N).

### 6c. Air Management During Filling

The bag is sealed — displaced air must exit back through the dip tube, creating counter-flow. At 2-5 PSI pump pressure, air compresses per Boyle's law, allowing ~85-90% fill on a single pump cycle. Multi-cycle fill-and-vent operations can achieve higher fill levels. For 1L bags, estimated fill time is 3-6 minutes with pump assist (vs 8-15 minutes gravity-only).

---

## 7. Mounting Hardware

### 7a. Connector End (Low Mount)

A 3D-printed snap-fit U-clip on the interior front wall grips the 28mm threaded cap. The user pushes the connector into the clip; friction and gravity hold it. Two clips: one at 30mm height (Bag 1), one at 73mm height (Bag 2).

### 7b. Sealed End (High Mount)

A standard 50mm binder clip (~$0.25) grips the heat-sealed seam. The clip's handles hook onto a 3D-printed J-hook on the rear wall or dock shelf underside. Two J-hooks positioned at the appropriate heights for each bag.

### 7c. Installation Sequence

1. Attach binder clip to bag's sealed seam
2. Hang binder clip on J-hook at rear of bag zone
3. Route connector down toward front
4. Push connector/cap into U-clip on front wall
5. Connect tubing (Platypus drink tube adapter already attached)

Estimated installation time: 15-30 seconds per bag.

### 7d. Complete Mount (Side View)

```
    ═══════════ DOCK SHELF UNDERSIDE ════════════
                                        ↓ J-hook (printed)
                                        │
                                   ┌────┤ binder clip
                                   │    │ grips sealed seam
                            ──────*────┘
                           / sealed end
                          /
                         /   BAG (inclined 18-20 deg)
                        /
                       /
                      /
            ─────────*
           / connector end
    ┌─────┤
    │U-clip│ (printed on front wall interior)
    │holds │ cap/connector
    └──────┘
    ═══════════ FLOOR PANEL ══════════════════════
    FRONT                                    BACK
```

---

## 8. Horizontal Cross-Section at Dock Height

At the dock shelf height (180mm), the dock and valve components occupy the space:

```
    TOP VIEW (at dock shelf height, 180mm)

    ┌──────────────────── 280mm ────────────────────┐
    │                                                │
    │  FRONT FACE                         BACK PANEL │
    │  │                                         │   │
    │  │  ┌── CARTRIDGE SLOT ─────┐              │   │
    │  │  │  150W x 130D          │   ┌────────┐ │   │
    │  │  │  (incl fitting wall)  │   │SOLENOID│ │   │
    │  │  │                        │   │CLUSTER │ │   │
    │  │  │                        │   │SV-D1   │ │   │
    │  │  │                        │   │SV-D2   │ │   │
    │  │  └────────────────────────┘   │SV-C1   │ │   │
    │  │                               │SV-C2   │ │   │
    │  │                               │NV, FM  │ │   │
    │  │                               └────────┘ │   │
    │  │                                         │   │
    │  │◄── 150mm dock ──►◄── ~120mm valves ──►│   │
    │                                                │
    └────────────────────────────────────────────────┘
```

The dock (150mm wide) sits on the left/center. Solenoid valves, needle valve, flow meter, and tees mount to the right of the dock on the shelf or on brackets attached to the right enclosure wall. The four solenoids (each ~80x35x45mm) arrange in a vertical column (~35mm wide x ~180mm tall) beside the dock.

---

## 9. Dimension Summary

### Active Design: 1L Bags, 400mm Height, Incline Mounting

| Dimension | Value |
|---|---|
| **Enclosure exterior** | **280W x 250D x 400H mm** |
| Wall thickness | 4mm |
| Interior | 272W x 242D x 392H mm |
| Floor panel | 0-4mm (4mm flat PETG) |
| Bag zone | 4-180mm (176mm) |
| Bag mounting angle | 18-20 degrees from horizontal |
| Dock shelf position | 180mm from floor |
| Dock shelf thickness | 6mm (180-186mm) |
| Cartridge cavity | 186-266mm (80mm) |
| Lever clearance | 266-306mm (40mm) |
| Electronics shelf | 306-310mm (4mm, open with cutouts) |
| Electronics zone | 310-400mm (90mm) |
| Cartridge slot center | ~226mm from floor (~9") |
| Weight (loaded) | ~7-8 kg (15-18 lbs) |

### Two-Bag Configuration

| Parameter | Bag 1 (Lower) | Bag 2 (Upper) |
|---|---|---|
| Connector center height | 30mm | 73mm |
| Sealed end center height | 107mm | 150mm |
| Sealed end top edge | 126mm | 169mm |
| Horizontal run | 238mm | 238mm |
| Width | 140mm (centered) | 140mm (centered) |
| Gap to next element | 5mm to Bag 2 | 11mm to dock shelf |

### Companion Machine Context

| Machine | Height | Width |
|---|---|---|
| Brio cold carbonated | 460mm | 220mm |
| Lillium cold carbonated | 440mm | 170mm |
| **Soda Flavor Injector** | **400mm** | **280mm** |

Our device is wider but shorter — it sits beside the companion machine as a clear accessory, not competing for visual dominance.

---

## 10. Historical Note

Prior analysis explored vertical hanging of 2L Platypus bags, which required a 500mm enclosure (280W x 250D x 500H mm) with a 265mm bag zone. That design was superseded by the 400mm height lock and the incline mounting approach, which solves the fundamental space problem without increasing enclosure height. The 2L vertical hanging analysis is preserved in earlier git history for reference.

---

## Sources

- [incline-bag-mounting.md](enclosure/research/incline-bag-mounting.md) — Incline geometry, two-bag stacking, mounting hardware, drainage analysis
- [dip-tube-analysis.md](enclosure/research/dip-tube-analysis.md) — Dip tube sealed path, orientation effects, flow restriction, dead volume
- [drip-tray-shelf-analysis.md](enclosure/research/drip-tray-shelf-analysis.md) — Drip tray removal justification, electronics shelf redesignation
- [pump-assisted-filling.md](enclosure/research/pump-assisted-filling.md) — Pump reversal fill method, topology correction, check valve design
- layout-spatial-planning.md — Enclosure master layout (280x250x400mm)
- cartridge-envelope.md — Cartridge dimensions (150W x 80H x 130D mm)
- hopper-and-bag-management.md — Bag dimensions, collapse analysis (historical)

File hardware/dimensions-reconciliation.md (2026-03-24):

# Dimensions Reconciliation — Authoritative Cross-Document Reference

This document is the single authoritative dimension table for enclosure layout and cartridge design. All other hardware documents defer to the values listed here.

Documents reviewed:
- `enclosure/research/layout-spatial-planning.md`
- `enclosure/research/incline-bag-mounting.md`
- `enclosure/research/drip-tray-shelf-analysis.md`
- `enclosure/research/dip-tube-analysis.md`
- `enclosure/research/pump-assisted-filling.md`
- `cartridge/planning/research/cartridge-envelope.md`
- `cartridge/planning/research/dock-mounting-strategies.md`
- `cartridge/planning/research/mating-face.md`
- `cartridge/planning/research/pump-mounting.md`
- `enclosure/research/hopper-and-bag-management.md`
- `cartridge/planning/requirements.md`

---

## 1. Resolved Design Decisions

### 1a. Enclosure Outer Dimensions

**280W x 250D x 400H mm** (front-loading tower layout).

280mm width accommodates dual hopper funnels and a wider cartridge slot. 250mm depth provides tube routing behind the dock. 400mm height is sufficient for the vertical stack. Older documents referencing a "Tall Tower" at 250x200x450 are superseded.

### 1b. Cartridge Envelope

**150W x 80H x 130D mm.**

Derived from verified Kamoer KPHM400 pump dimensions (115.6 x 68.6 x 62.7 mm) with a bottom-up buildup in cartridge-envelope.md:
- **Width 150:** Two pumps side-by-side = 137.2mm + 5mm center gap + 6mm walls = 148mm, rounded to 150mm.
- **Height 80:** Two pumps = 62.7mm + 10mm tube routing + 6mm walls = 78.7mm, rounded to 80mm.
- **Depth 130:** Pump = 115.6mm + 5mm cam housing + 6mm walls = 126.6mm, rounded to 130mm.

Older documents referencing 140x90x100 predate the pump arrangement analysis. The 100mm depth is physically impossible (the pump alone is 115.6mm).

### 1c. Cartridge Weight

**~820g** (~1.8 lbs).

Component-by-component buildup from cartridge-envelope.md:
- 2x pumps at 306g = 612g
- Tubing, fittings, housing, hardware = ~208g

The 940g figure in older documents is a pre-rewrite estimate. Treat 940g as a conservative upper bound for structural calculations.

### 1d. Bag Zone and Mounting Approach

**Bags mount at 18-20 degrees incline (two-point stretch), not vertical hanging or flat cradles.**

The conflict between "100mm flat cradle zone" (layout-spatial-planning.md) and "250-300mm vertical hanging zone" (dock-mounting-strategies.md, hopper-and-bag-management.md) is resolved by the incline mounting approach (incline-bag-mounting.md):

- Each 1L Platypus bag (~250mm long) is stretched between a low mount point (connector at front) and a high mount point (sealed end at rear)
- At 18 degrees: horizontal run = 238mm (fits 242mm interior depth), vertical rise = 77mm per bag
- Two bags stack vertically in the same depth footprint with a thin divider between them
- The dip tube extends from the low connector end upward along the incline, remaining submerged until the bag is nearly empty (last 5-10%)
- Two-point tension constrains collapse to thinning-in-place rather than random folding

Bag zone height requirement for two stacked 1L bags at 18 degrees:
- Bag 1 connector center at ~26mm, top of sealed end at ~122mm
- Bag 2 connector center at ~69mm, top of sealed end at ~165mm
- Total bag zone: ~165-175mm depending on exact angle and clearances

### 1e. Drip Tray Removed

The 15mm drip tray is removed (drip-tray-shelf-analysis.md). The floor is a flat 4mm panel. Rationale:
- No bag swapping (bags are permanent, refilled via hopper)
- No condensation (no refrigeration inside enclosure)
- No open liquid surfaces during operation (fully sealed fluid path)
- The only realistic slow-leak scenario (loose zip tie at bag connector) is better solved with hose clamps
- 15mm recovered for the bag zone

### 1f. Drip Shelf Redesigned as Electronics Shelf

The "drip shelf" at ~306mm is retained as a structural electronics shelf but is no longer a sealed liquid barrier (drip-tray-shelf-analysis.md). It is an open shelf with cutouts for wiring and airflow, providing:
- DIN rail mounting surface
- Structural stiffness (ties side walls together)
- Visual/physical zone separation for assembly

Liquid cannot travel upward from the plumbing zone to the electronics zone under gravity. The "drip" designation is dropped.

### 1g. Back Panel Drip Dam Removed

The drip dam ridge on the back panel is unnecessary. Water fittings are at the bottom, electrical connections at the top. Gravity keeps water away from electronics. The vertical arrangement is sufficient protection.

### 1h. Height Constraint: Cartridge in Dock Slot

The 400mm layout allocates a ~126mm dock+valves zone (180-306mm), providing the 80mm cartridge with ~46mm of clearance for valves, lever swing, and tolerances. This is comfortable for FDM printing. The earlier concern about 5mm margin in the Tall Tower layout no longer applies.

### 1i. Hopper Connection Topology

The hopper connects at the pump outlet side, not at the bag-side tee (pump-assisted-filling.md). During refill, the pump reverses to pull concentrate from the hopper through the pump and into the bag. This corrects the earlier topology assumption in hopper-and-bag-management.md. The change affects plumbing routing but not enclosure dimensions.

### 1j. Dip Tube Creates Sealed Path

The Platypus Drink Tube Kit creates a sealed bag-to-tubing path through the dip tube (dip-tube-analysis.md). The bag is not an "open pouch" — fluid must travel through the dip tube. This validates:
- Bidirectional flow (dispensing and hopper refill both work through the same sealed path)
- Clean cycle fill (house water pressure pushes through the dip tube into the bag)
- The incline mount's drainage reliability (dip tube extends upward into the liquid pool)

---

## 2. Authoritative Dimension Table

### 2a. Enclosure

| Parameter | Value | Notes |
|---|---|---|
| **Outer dimensions (W x D x H)** | **280 x 250 x 400 mm** | Front-loading tower layout |
| Wall thickness | 4mm | All sides |
| Internal dimensions (W x D x H) | 272 x 242 x 392 mm | Outer minus 2x wall thickness |
| Footprint | 700 cm^2 | Smaller than a cereal box laid flat |
| Estimated weight (loaded, 2 bags full) | ~6-7 kg | Two 1L bags instead of 2L |

### 2b. Zone Heights (floor = 0mm, INCLINE MOUNT configuration)

| Zone | Floor (mm) | Ceiling (mm) | Height (mm) | Contents |
|---|---|---|---|---|
| Floor panel | 0 | 4 | 4 | Flat 4mm panel (no drip tray) |
| Bag zone | 4 | ~180 | ~176 | Two 1L bags on incline mounts (18-20 deg), stacked vertically |
| Dock shelf | ~180 | ~186 | ~6 | Structural horizontal member |
| Dock + valves | ~186 | ~306 | ~120 | Cartridge dock (80mm H), solenoid valves, tees, flow meter, needle valve, tube routing |
| Electronics shelf | ~306 | ~310 | ~4 | Open structural shelf with cutouts for wiring and airflow |
| Electronics | ~310 | ~396 | ~86 | ESP32, 3x L298N, RTC, MCP23017, fuse block, DIN rail |
| Hopper | ~396 | 400+ | Extends above | Two funnels at front-top corner, caps when not in use |

### 2c. Cartridge

| Parameter | Value | Source |
|---|---|---|
| **Envelope (W x H x D)** | **150 x 80 x 130 mm** | cartridge-envelope.md buildup from pump dims |
| Volume | ~1.56 L | |
| Weight | ~820g (~1.8 lbs) | Component-by-component buildup |
| Pump (Kamoer KPHM400) | 115.6 x 68.6 x 62.7 mm, 306g each | Verified from Kamoer specs |
| Pump arrangement | Side-by-side, motors same direction | Only arrangement that fits height |
| Housing construction | Tray + shell + lid (3-piece PETG) | pump-mounting.md recommendation |
| Housing wall thickness | 3mm per side | |

### 2d. Cartridge Slot and Dock

| Parameter | Value | Source |
|---|---|---|
| Slot opening (with chamfer) | 155W x 105H mm | layout-spatial-planning.md |
| Slot chamfer | 5mm at 45 deg, all edges | Funnel for sloppy insertion |
| Cartridge-in-slot clearance (height) | 10-20mm above 80mm cartridge | 400mm layout provides comfortable margin |
| Guide rail clearance | 0.3-0.5mm per side (PETG) | guide-alignment.md |
| Dock shelf width | ~264mm (272mm interior minus ~4mm clearance/side) | |
| Dock shelf depth | ~234mm (242mm interior minus clearance) | |
| Dock shelf thickness (floor) | 6mm | Structural minimum for PETG span |
| Dock fitting wall height | ~100mm | Houses JG fittings + pogo pins + guide rail attachment |
| Dock fitting wall thickness | 6mm | Bulkhead fitting nut clamping surface |

### 2e. Mating Face and Connections

| Parameter | Value | Source |
|---|---|---|
| Tube port layout | 2x2 grid, 15mm center-to-center | mating-face.md |
| Port zone footprint | 33.5 x 33.5 mm | |
| Tube stub OD | 6.35mm (1/4") hard nylon/PE | |
| Tube stub total length | ~29-30mm from inside wall | mating-face.md |
| John Guest fitting body OD | ~12.7mm | collet-release.md |
| Release plate | 6mm thick, 3mm travel | |
| Alignment pins (dock side) | 2-4 tapered, 15-20 deg, 8-10mm base | guide-alignment.md |
| Electrical pads (cartridge top) | 3x flat pads, 10 x 5mm, 10mm C-C | electrical-mating.md |
| Pogo pins (dock ceiling) | 3x spring-loaded | |

### 2f. Depth Budget (within dock zone)

| Zone | Depth (mm) | Contents |
|---|---|---|
| Cartridge body | 130 | Pumps, tubing, release plate, cam housing |
| Dock back wall + fittings | ~35 | 5mm wall, ~25mm JG fitting depth, ~5mm alignment pin protrusion |
| Tube routing behind dock | ~22-27 | Silicone tubing from JG fittings to vertical runs |
| **Total** | **~187-192** | Fits within 242mm interior depth with ~50mm to spare |

### 2g. Bag Dimensions

**Primary: Platypus 1L bags** (active design, locked by 400mm enclosure height decision)

| Parameter | Value | Notes |
|---|---|---|
| Length | ~250mm | Connector end to sealed end |
| Width | ~140mm | Across the bag face |
| Thickness (when full) | ~40mm | |
| Connector | 28mm standard bottle thread, single opening | |
| Dip tube | 1/4" ID PU tube, extends ~100-150mm into bag interior | Platypus Drink Tube Kit |

**Reference: Platypus 2L bags** (not used in current design)

| Parameter | Value | Notes |
|---|---|---|
| Length (when full) | 250-300mm (corrected from 350mm) | layout-spatial-planning.md Section 2c |
| Width | 190mm | |
| Thickness (when full) | 60-80mm | |

### 2h. Incline Mount Geometry (Two 1L Bags)

| Parameter | Value |
|---|---|
| Incline angle | 18-20 degrees from horizontal |
| Horizontal run per bag | 235-238mm (of 242mm available) |
| Bag 1 connector center height | ~26-30mm |
| Bag 1 sealed end top | ~122-134mm |
| Bag 2 connector center height | ~69-78mm |
| Bag 2 sealed end top | ~165-169mm |
| Gap between bags | ~5mm |
| Clearance to dock shelf | ~11-15mm |
| Width consumed | 140mm of 272mm (66mm per side for tubing) |
| Lower mount | Snap-fit U-clip for connector cap (printed on front wall) |
| Upper mount | Binder clip on J-hook for sealed seam (printed on rear wall / shelf underside) |

---

## 3. Remaining Questions Requiring Physical Measurement

1. **Platypus 1L bag actual dimensions**: Measure a filled 1L Platypus bag. Is it 250mm long, 140mm wide, 40mm thick? The incline geometry analysis depends on these inputs.

2. **Dip tube length**: Measure how far the Platypus Drink Tube Kit dip tube extends into the bag interior. This determines the last-liquid threshold.

3. **Incline drainage test**: Mount a filled 1L bag at 18-20 degrees (two nails in a board, binder clips). Pump it dry. At what remaining volume does air appear? Does the dip tube extend the useful range as predicted?

4. **Two-bag clearance verification**: With two bags physically mounted, verify the 5mm inter-bag gap and the 11mm clearance to the dock shelf. Full bags may deform slightly.

5. **Kamoer KPHM400 mounting hole pattern**: Measure center-to-center distances on the actual bracket. The cartridge tray design depends on this.

6. **Kamoer KPHM400 full envelope with barbs**: Measure the pump with barbs attached. The 62.7mm height does not include barb protrusion (~15-20mm above the pump body). If barbs protrude more than 10mm above the body, the cartridge height increases.

7. **John Guest fitting body clearance at 15mm C-C**: Test whether the specific fittings in hand can mount at 15mm center-to-center. If hex flats or molding flash prevent this, the spacing must increase to 18mm C-C.

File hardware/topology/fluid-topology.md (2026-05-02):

# Soda Machine Fluid Topology

## Valves

| Valve | Purpose |
|---|---|
| V-A | Tap water inlet gate |
| V-B | Hopper funnel gate |
| V-C | Shared source → Pump A (channel A select) |
| V-D | Shared source → Pump B (channel B select) |
| V-E | Bag A → Pump A inlet |
| V-F | Pump A outlet → Bag A |
| V-G | Pump A outlet → Nozzle A |
| V-H | Bag B → Pump B inlet |
| V-I | Pump B outlet → Bag B |
| V-J | Pump B outlet → Nozzle B |
| V-K-A | BiB A inlet gate (channel A) |
| V-K-B | BiB B inlet gate (channel B) |

All valves are normally closed solenoid valves. Flow direction is inlet (I) to outlet (O) only.

## Y-Junctions

| Junction | Port 1 | Port 2 | Port 3 |
|---|---|---|---|
| Y-A | V-A-O (tap water) | V-B-O (hopper) | Y-B-1 (to channel split) |
| Y-B | Y-A-3 (from tap/hopper merge) | V-C-I (channel A select) | V-D-I (channel B select) |
| Y-KA | V-C-O (channel A shared source) | V-K-A-O (channel A BiB) | Y-C-1 (to pump A inlet) |
| Y-C | Y-KA-3 (channel A source merge) | V-E-O (bag A to pump return) | P-A-I (pump A inlet) |
| Y-D | P-A-O (pump A outlet) | V-F-I (pump to bag A) | V-G-I (pump to nozzle A) |
| Y-E | V-F-O (pump to bag A return) | Bag A port | V-E-I (bag A to pump) |
| Y-KB | V-D-O (channel B shared source) | V-K-B-O (channel B BiB) | Y-F-1 (to pump B inlet) |
| Y-F | Y-KB-3 (channel B source merge) | V-H-O (bag B to pump return) | P-B-I (pump B inlet) |
| Y-G | P-B-O (pump B outlet) | V-I-I (pump to bag B) | V-J-I (pump to nozzle B) |
| Y-H | V-I-O (pump to bag B return) | Bag B port | V-H-I (bag B to pump) |

## Tube Segments

### Shared

| # | From | To | Notes |
|---|---|---|---|
| 1 | Tap water source | Flow regulator inlet | |
| 2 | Flow regulator outlet | V-A-I | |
| 3 | V-A-O | Y-A-1 | |
| 4 | Hopper funnel bottom | V-B-I | |
| 5 | V-B-O | Y-A-2 | |
| 6 | Y-A-3 | Y-B-1 | |
| 7 | Y-B-2 | V-C-I | |
| 8 | Y-B-3 | V-D-I | |

### Channel A

| # | From | To | Notes |
|---|---|---|---|
| 9 | BiB A connector | V-K-A-I | |
| 10 | V-K-A-O | Y-KA-2 | |
| 11 | V-C-O | Y-KA-1 | |
| 12 | Y-KA-3 | Y-C-1 | |
| 13 | V-E-O | Y-C-2 | |
| 14 | Y-C-3 | P-A-I | |
| 15 | P-A-O | Y-D-1 | |
| 16 | Y-D-2 | V-F-I | |
| 17 | V-F-O | Y-E-1 | |
| 18 | Bag A port | Y-E-2 | |
| 19 | Y-E-3 | V-E-I | |
| 20 | Y-D-3 | V-G-I | |
| 21 | V-G-O | Nozzle A | |

### Channel B

| # | From | To | Notes |
|---|---|---|---|
| 22 | BiB B connector | V-K-B-I | |
| 23 | V-K-B-O | Y-KB-2 | |
| 24 | V-D-O | Y-KB-1 | |
| 25 | Y-KB-3 | Y-F-1 | |
| 26 | V-H-O | Y-F-2 | |
| 27 | Y-F-3 | P-B-I | |
| 28 | P-B-O | Y-G-1 | |
| 29 | Y-G-2 | V-I-I | |
| 30 | V-I-O | Y-H-1 | |
| 31 | Bag B port | Y-H-2 | |
| 32 | Y-H-3 | V-H-I | |
| 33 | Y-G-3 | V-J-I | |
| 34 | V-J-O | Nozzle B | |

---

## Operations — Valve States

Open valves listed; all others closed.

This table is canonical for the integrated flavor manifold. Pumps run forward only. Valve state, not pump reversal, selects whether a pump draws from a bag, hopper, BiB input, or tap-water source and whether the outlet returns to a bag or goes to the nozzle. Stopped peristaltic pumps are not used as shutoff valves; normally closed solenoid valves define the closed state and keep the dispense paths primed.

### Dispense A

- Open: V-E, V-G
- Pump A: ON
- Path: Bag A → V-E → P-A → V-G → Nozzle A

### Dispense B

- Open: V-H, V-J
- Pump B: ON
- Path: Bag B → V-H → P-B → V-J → Nozzle B

### Fill from Hopper → Bag A

- Open: V-B, V-C, V-F
- Pump A: ON
- Path: Hopper → V-B → V-C → P-A → V-F → Bag A

### Fill from Hopper → Bag B

- Open: V-B, V-D, V-I
- Pump B: ON
- Path: Hopper → V-B → V-D → P-B → V-I → Bag B

### Fill from BiB → Bag A

- Open: V-K-A, V-F
- Pump A: ON
- Path: BiB A → V-K-A → P-A → V-F → Bag A

### Fill from BiB → Bag B

- Open: V-K-B, V-I
- Pump B: ON
- Path: BiB B → V-K-B → P-B → V-I → Bag B

### Clean Water Fill → Bag A

- Open: V-A, V-C, V-F
- Pump A: OFF (line pressure through idle pump)
- Path: Tap → V-A → V-C → P-A (idle) → V-F → Bag A

### Clean Water Fill → Bag B

- Open: V-A, V-D, V-I
- Pump B: OFF (line pressure through idle pump)
- Path: Tap → V-A → V-D → P-B (idle) → V-I → Bag B

### Clean Flush A (water out)

- Open: V-E, V-G
- Pump A: ON
- Path: Bag A → V-E → P-A → V-G → Nozzle A
- (Same as Dispense A)

### Clean Flush B (water out)

- Open: V-H, V-J
- Pump B: ON
- Path: Bag B → V-H → P-B → V-J → Nozzle B
- (Same as Dispense B)

### Air Purge In → Bag A

- Open: V-B, V-C, V-F
- Pump A: ON
- Funnel: dry, open to air
- Path: Air → V-B → V-C → P-A → V-F → Bag A
- (Same path as hopper fill)

### Air Purge In → Bag B

- Open: V-B, V-D, V-I
- Pump B: ON
- Funnel: dry, open to air
- Path: Air → V-B → V-D → P-B → V-I → Bag B

### Air Purge Out A

- Open: V-E, V-G
- Pump A: ON
- Path: Bag A → V-E → P-A → V-G → Nozzle A
- (Same as Dispense A)

### Air Purge Out B

- Open: V-H, V-J
- Pump B: ON
- Path: Bag B → V-H → P-B → V-J → Nozzle B
- (Same as Dispense B)

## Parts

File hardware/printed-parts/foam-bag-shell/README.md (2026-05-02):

# Foam-bag shell

3D-printed PETG enclosure for the soda machine's "cold core" — the
back-of-enclosure subsystem that holds the carbonator pressure vessel, the
copper evaporator coil wrapped around it, and two flavor bladders in
pockets on opposite sides. Pour-in-place polyurethane foam fills the
cavities around the wetted/cold parts for thermal insulation.

## Coordinate convention

The CadQuery script uses an explicit XZ plane with +Y normal
(`xz_plane_y_up`), so geometry grows upward in +Y.

- **Y** is vertical. The floor sits at y=0; everything stacks upward from
  there.
- **X** is the bag axis. Two bag pockets sit on opposite sides along X.
- **Z** is perpendicular to the bag axis.

## Physical inputs

- **Pressure vessel** — 5.000" OD × 0.065" wall × 6.000" cut length 316 SS
  welded tube (OnlineMetals #12498). Two 1/4"-thick 316 SS endcap plates
  laser-welded internally, recessed flush with the tube ends. Hand-tapped
  1/4" NPT, four ports total — two top plate (water inlet, PRV), two
  bottom plate (CO2 inlet, water outlet). Vessel assembled height = tube
  length = **152.4 mm**. Outer radius = **63.5 mm**.
- **Bag** — Platypus-style soft-walled bladder, 1 L max but used at
  ≤ 750 mL. Single port at the cap end with a 90° turn. Filled envelope,
  posed cap-down: **125 mm wide (along Z) × 35 mm deep (along X, radially
  outward) × 225 mm tall**. Two bags per cold core.
- **Evaporator coil** — 1/4" OD × 0.187" ID × 0.031" wall ACR copper,
  hand-wound helically around the vessel exterior, bonded with 3M 425
  aluminum foil tape. ~6.35 mm radial occupancy plus tolerance — budgeted
  at 7 mm (`copper_coil_buffer_radius`).
- **Tank-port fittings** — 1/4" NPT 90° elbows on every port, turning the
  line laterally. ~30 mm vertical envelope per elbow above and below the
  tank.

## Shells

The geometry is built up from open-topped shells, each printed as a
separate solid and unioned together. **All shells use 1 mm wall and floor
thickness** (`wall_and_floor_thickness`).

### tank_copper_shell

Round cup that contains the pressure vessel and the copper coil zone
wrapped around it. Outer radius **70.5 mm** (tank radius 63.5 + coil-zone
buffer 7). Total height **212.4 mm** (tank height 152.4 + 30 mm above +
30 mm below for the 90° elbow space).

### tank_support_wedge

Annular wedge ring sitting inside the lower portion of the
tank-copper-shell, holding the tank up by its outer rim. The wedge's
outer face is coincident with the tank-copper-shell's inner wall (at
R = 69.5).

The top face of the wedge is a flat annular plateau, **15 mm wide**
(R = 54.5 to R = 69.5), where the tank's outer rim rests. The inside of
the wedge has a 45° slope from (R = 69.5, y = 1) up and inward to
(R = 54.5, y = 16), then continues straight up as a vertical inner face
to the plateau at y = 31.

Inboard of R = 54.5 (and below the plateau) is open volume — so the
tank's bottom-plate fittings have unobstructed downward space, and pour
foam fills around them.

### bag_pocket_support_shell

Square cup encompassing the tank-copper-shell. **141 × 141 mm** in
plan-view, sized so that the square's wall centerlines are tangent to the
tank-copper-shell's wall centerline at the four cardinal axis points.
Same total height as the tank-copper-shell. The four corners of the
square's floor extend beyond the round cup's footprint; everywhere the
two floors overlap (inside the inscribed circle), they coincide and the
union produces no change.

### bag_pocket_shell (one of two)

Rectangular cup attached to one side of the bag_pocket_support_shell.
**35 mm deep (along X) × 125 mm wide (along Z) × 212.4 mm tall**. The
pocket's tank-facing wall is coincident with the bag_pocket_support_shell's
+X wall.

A second `bag_pocket_shell` mirrored on the −X side is built the same
way (`build_a_bag_pocket_shell(side=-1)`) and unioned alongside the
first.

## Penetrations

Seven holes total, all sized for **1/4" OD tubing (6.35 mm)** plus a small
clearance for fit and seal:

| # | Hole | Carries |
|---|---|---|
| 1, 2 | Bag-pocket flavor line (×2) | 1/4" OD soft tubing from each bag's cap to its peristaltic pump |
| 3, 4 | Evaporator coil suction & liquid (×2) | 1/4" OD copper refrigerant lines to/from the compressor |
| 5 | Water inlet | 1/4" OD line from the diaphragm pump |
| 6 | CO2 inlet | 1/4" OD line from the regulator |
| 7 | Carbonated water outlet | 1/4" OD line to the dispense faucet |

**Build decision:** for the water inlet and CO2 inlet, the supply-side
tubing reduces to 1/4" OD *before* reaching the shell wall — i.e., the
transition fittings (3/8" barb-to-NPT adapter, 5/16" push-to-connect,
1/4" NPT check valves, etc.) all live on the warm side of the shell.
Inside the shell, every penetration is the same 1/4" OD. This keeps
holes small, uniform, and simple to seal during foam pour, at the cost
of the transition fittings being a few cm further from the tank.

## Coincident-wall principle

Wherever two shells share a boundary, their walls are positioned so they
**overlap exactly in 3D space** — same outer face, same inner face —
rather than sitting side-by-side. After union, that boundary is one
wall's worth of material (1 mm), not two (2 mm).

This drives several dimension choices:

- The **bag_pocket_support_shell** has its half-side equal to the
  tank_copper_shell's outer radius, so the square's wall centerline meets
  the circle's wall centerline at the four cardinal points (their walls
  coincide there).
- The **bag_pocket_shell** is offset by
  `tank_copper_shell_radius + depth/2 - wall_thickness`, so its inner
  wall coincides with the bag_pocket_support_shell's +X wall.
- The **tank_support_wedge**'s outer face coincides with the
  tank_copper_shell's inner wall.

## Reference

- [`../pump-case/generate_step_cadquery.py`](../pump-case/generate_step_cadquery.py)
  — gold standard for the PETG-enclosure pattern in this repo.

The cadquery venv lives at `tools/cad-venv/bin/python` (cadquery is not
on system Python).

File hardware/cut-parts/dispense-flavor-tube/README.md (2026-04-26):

# Dispense Flavor Tube — Bent 1/4" 316 SS

Visual-companion tube. Two of these pass through 1/4" holes in the
mounting plate of the installed Westbrass A2031-NL-62 8" Touch-Flo
(factory faucet untouched) and arc up over to terminate near the
factory spout tip — one per flavor line.

**Approximate geometry, Xometry rough-quoting only.** Geometry was
hand-eyeballed by the user against the installed faucet on 2026-04-24:

| Segment | Value |
|---|---|
| Bottom straight (40 mm below deck + 65 mm above) | 105 mm |
| Bend 1 | 30° at R 31.75 mm (1.25") *(snapped from 40 mm guess)* |
| Mid straight | 100 mm |
| Bend 2 | 90° at R 31.75 mm (1.25") *(snapped from 40 mm guess)* |
| Tip straight | 15 mm |

Resulting envelope: ~4.5" forward × ~8.9" tall, centerline ~11.3",
mass ~45 g per tube (316 SS, 0.049" wall).

**Xometry quoter constraints (learned 2026-04-25):** CLR/OD ratio must
be 2:1–5:1; CLR must be a 0.25" increment; on 1/4" OD, only 0.049"
and thicker walls are actually stocked despite the capabilities page
listing 0.035" as the minimum.

## Open problem — single-CLR constraint vs. real Touch-Flo asymmetric radii

A photo-measurement pass against a Westbrass D2031 spec image and a
clean side-view product photo (2026-04-25) showed the real Touch-Flo
gooseneck has **two different bend radii** — bend 1 ≈ 12 mm CLR,
bend 2 ≈ 48 mm CLR. Xometry's tube-bending DFM page recommends a
single CLR per part "for ease of manufacturability" — multi-CLR parts
need either multi-stack tooling or an additional setup, which the
quoter charges for (or refuses entirely).

The current STEP uses **one** CLR (1.25" / 31.75 mm) for both bends,
which is the largest legal value Xometry will accept for 1/4" OD
(5:1 ratio cap). That oversells bend 1 (off by ~2.6×) and undersells
bend 2 (off by ~1.5×). The silhouette drifts from the real faucet
visibly, especially at the upper transition.

**Status:** documented, not solved. Two paths forward if the silhouette
mismatch turns out to matter:
- Try a tube-bending shop that supports multiple CLRs per part natively
  (most niche tube benders do; instant-quote services tend not to). This
  generally means custom-quote workflows and longer lead times.
- Accept the single-CLR approximation and adjust adjacent geometry
  (mid-straight length, sweep angles) to recover apparent silhouette
  fidelity even with a single CLR.

**Tube-bending alternatives surveyed (2026-04-25):**
- **OSH Cut** — instant-quote tube bending in-browser, similar UX to
  SendCutSend. Supports steel and 304 SS only (no 316 listed in their
  tube stock); OD range 0.75"–1.5" is also above our 0.25". Not viable
  for this part as currently spec'd.
- **Niche tube-bending shops** (Tube-Tec, Triad Products, Noble
  Industries, Woolf Aircraft) — handle multi-CLR parts routinely but
  use email/RFQ workflows, not instant quoting.

## Xometry quotes (2026-04-25)

Submitted as: **316 SS**, 1/4" OD × 0.049" wall, MIL Flat Black powder
coat, matte sheen, bag-and-tag poly-bag finish-side packaging.

| Qty | Total | $/part |
|---:|---:|---:|
| 6 | $819 | $137 |
| 20 | $1,422 | $71 |
| 100 | $2,937 | $29 |

Per-part cost crashes hard between 6 and 100 — the bender setup amortizes
across the run. At 100 units the all-in landed cost per machine for two
tubes is ~$58, vs ~$274 at the 6-tube hand-build batch.

**Xometry submission spec for re-quotes:** 316 SS, 0.049" wall, MIL Flat
Black powder coat, matte sheen, bag-and-tag poly. Quantity = 2 per
finished machine. See `hardware/harvested/touch-flo-faucet/xometry-submission-notes.md`
for the broader quote-form checklist (including the grit-blast
pre-treatment note for 304/316 SS powder adhesion).

Regenerate: `tools/cad-venv/bin/python generate_step_cadquery.py`

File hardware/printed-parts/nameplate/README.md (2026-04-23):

# Rear-Panel Nameplate

3D-printed serialized plaque mounted on the rear face of the enclosure. Visible after install. One plaque per unit.

## What this does

Three distinct jobs overlap onto the same artifact:

1. **Safety communication.** The plaque states input voltage, frequency, and power rating, and carries a prominent "120V 60Hz only — not for 240V" warning to offset the "250V 10A" spec stamp molded into the C14 chassis inlet mounted below it (standard C14 component rating vs. actual appliance rating — see commit `45e22ef` discussion). This matters whether or not we ever carry a listing: it tells the user, and any electrician they consult during install, what the appliance actually wants.

2. **Founder Edition identity.** Per `marketing/target-market.md`, units 001–050 are hand-built, numbered, and signed by the founder. This plaque is where the number and signature live. The plaque is the physical proof that a specific person built this specific machine — the Founder Edition story made tangible.

3. **Per-unit QR code + serialization.** Links the physical machine to a unique persistent URL, `homesodamachine.com/u/NNN` where NNN is the unit number, zero-padded (`001`, `002`, ..., `050`). The serial number printed on the plaque ties this specific unit to a support/warranty record we can look up by QR scan. What that URL resolves to is a future customer-portal decision — the QR is the binding, and the destination can evolve without changing the physical plaque.

Standard Edition (units 051+) is out of scope for this revision. Revisit if/when Founder Edition sells through.

## What this is *not*

The Founder Edition is not UL-listed or ETL-listed, and pursuing listing is not planned at this stage — $15k–40k+ per model of initial testing plus annual fees is not economic for a 50-unit run at $7,500/unit, listing is not legally required for a cord-and-plug D2C household appliance, and a hand-built run can't really demonstrate the production-consistency audit a listing requires.

The plaque's content *happens* to resemble what a UL-listed product would carry because voltage/serial/power markings are just good product hygiene. But the framing is safety + traceability + identity, not regulatory compliance, and the plaque does not display a UL or ETL mark. If listing ever becomes worth pursuing later (retail channel, commercial expansion, insurance pressure), the plaque data is already in the right shape and the design revises to add the mark.

## Content layout

Content spec, not visual design. Final layout, typography, and dimensions TBD.

```
HOME SODA MACHINE
Founder Edition — No. 027 of 050

Signed: [handwritten signature]

Model: SFI-1
Serial: SFI1-FE-027
Input: 120V AC  60Hz  5A  600W

⚠ 120V 60Hz ONLY — not for 240V

[QR code]   homesodamachine.com/u/027
```

## Why printed separately from the enclosure

The nameplate has finer text and tighter features than anything else on the appliance. Printing it as part of the enclosure would force the entire enclosure to use nameplate-grade print settings, which is the wrong trade. Even if the plaque eventually bonds to the enclosure, it is a separate print operation with its own settings.

- **Nozzle:** 0.2 mm (vs. 0.4 mm for bulk enclosure parts)
- **Layer height:** 0.08–0.12 mm
- **Contrast strategy:** two-color inlay — dark body with light recessed text and QR, or the inverse. Filament change at the text-surface layer. No paint; survives kitchen wipe-down.
- **Signature fidelity:** likely beyond FDM capability at the quality level this plaque deserves. Current direction: **laser-engrave the signature** onto the printed plaque after printing, preserving a pen-traced vector. Decision deferred until the first plaque prints and we see how the text + QR portions land. Text and QR render acceptably with FDM two-color inlay; the signature is the one element that probably doesn't.

## Per-unit generation (planned)

The CadQuery script (to be written) will take these parameters:

- `unit_number` — integer, 1 through 50
- `qr_png_path` — QR code PNG generated by `qrcode` Python package from `https://homesodamachine.com/u/{unit_number:03d}`
- `signature_svg_path` — placeholder flat-text rendering until the laser-engrave workflow is decided

and emit a unit-specific STEP file. Generating all 50 plaques up front is trivial; storage is negligible.

## Mounting

Interfaces with the rear panel of the enclosure — specifics TBD once the enclosure itself reaches design. Likely candidates: M3 countersunk screws through corner bosses, magnetic attachment over a recessed pocket, or an interference-fit dovetail recessed into the rear panel. Revisit when the enclosure design is ready.

## Files (planned)

- `generate_step_cadquery.py` — parametric generator (not yet written)
- `nameplate-NNN.step` — per-unit outputs, generated on demand
- `qrcodes/NNN.png` — per-unit QR code PNGs, generated alongside

Run with `tools/cad-venv/bin/python` per the hardware context file.

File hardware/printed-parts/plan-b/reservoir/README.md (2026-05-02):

# Printed Flavor Reservoir

Plan B for replacing the permanent Platypus bladders with custom hard reservoirs that conform to the cold-core envelope. The user-visible experience stays the same: flavor lives inside the machine, dispenses instantly, fills from the top hopper or rear BiB input, and cleans in place. This plan exists because under-sink volume is tight enough that an off-the-shelf bottle's extra cap, handle, shoulder, and clearance features cost real appliance volume.

The reservoir is not the carbonator and is not a service pressure vessel. It is a vented syrup reservoir that must reliably hold flavor concentrate, survive pump suction and fill/clean cycles, fit the thermal envelope, and not create dead syrup pockets.

For Plan B, the fluid reservoir remains a separate printed part from the foam-bag shell. Printing the reservoir and foam shell as one integrated part may be possible, but it couples leak integrity, foam-pour geometry, print failure, cleaning access, and service replacement into one experiment. That belongs in a later Plan C, not in the first hard-reservoir path.

## Serviceability Constraint

Plan B is intended to be a lifetime wetted part in normal use, but not a potted or sacrificial cold-core component. The foam cap / shell stack must preserve a non-destructive service path: removable dowels, screws, or heat-set-insert fasteners are acceptable, but glue in the reservoir access path is not. Reservoir replacement may require appliance disassembly, but it must not require cutting foam, cutting tubing, disturbing the refrigeration loop, or replacing the cold core.

## Candidate Filament

Initial test prints should use natural / uncolored PET-family material with explicit food-contact paperwork available from the seller or manufacturer. Buy small quantities first; this phase is about proving print process and reservoir behavior, not locking a production supplier.

| Candidate | Purchase link | Current purchase notes checked 2026-05-02 | Why it is in the test set |
|---|---|---|---|
| CARBON by Comfy Materials certified food-grade PETG, 1.75 mm, 1 kg | [Comfy Materials direct](https://comfymaterials.com/product/certified-food-grade-petg-3d-printer-filament-carbon-by-comfy-materials-lab-tested-fda-compliant-food-safe-1-75mm-1kg-accuracy-0-0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) | $34.99-$35.99; seller contact page lists Tampa, FL; direct product page allows add-to-cart but does not state stock count or lead time. | Strongest retail claim found: Eastman GN071 copolyester, NSF/ANSI 51 raw resin, claimed TÜV SÜD + SGS testing to FDA 21 CFR 177.1630. Good first material for liquid-hold and process tests. |
| Fillamentum PETG Natural, 1.75 mm, 1 kg | [Fillamentum USA](https://fillamentumusa.com/products/petg-natural-1) | $30.00; page states "Low stock - 7 in stock, ready to ship" and also has a Shopify backorder notice for the selected variant, so confirm at checkout. Site states orders before 11:00 CET ship same day and average delivery is 2-4 days worldwide. | Natural PETG with food-contact declaration available by request; good second source for comparing printability, taste/odor, and long-dwell syrup behavior. |

Use a dedicated stainless nozzle/hotend path for this work, and keep non-test filaments away from it while hot.

## Reservoir Architecture Under Test

Target features for the first design:

- One reservoir per flavor, shaped to the cold-core shell instead of shaped like a bottle.
- 1 L usable volume target, with any extra volume treated as headspace and drain margin.
- Sloped internal floor to a low outlet sump.
- Outlet boss sized for the same 1/4" hard-line ecosystem used elsewhere in the flavor manifold.
- High vent port with a replaceable hydrophobic membrane filter, protected by a splash labyrinth or short standpipe.
- Fill path from the valve manifold, not a user-opened cap on the reservoir.
- No internal support material, no internal threads, no decorative texture, no sharp inside corners.

Current `../foam-bag-shell/` CadQuery creates two mirrored bag-pocket shells. Each current pocket has a gross envelope of 35.0 mm X × 143.0 mm Z × 212.4 mm Y = 1.063 L, and an internal void of roughly 33.0 mm X × 141.0 mm Z × 211.4 mm Y = 0.984 L. A true 1 L printed reservoir is therefore close enough to today's package that Plan B should start by enlarging the bag-pocket gross envelope slightly in X only. Avoid growing Y or Z unless the pressure-vessel, fitting, or enclosure stack changes elsewhere.

The first printable shape can be ugly. It needs to preserve the real wall thicknesses, bosses, vent geometry, outlet sump, and sealing surfaces. Exterior packaging elegance comes after the liquid behavior is proven.

## Test Sequence

Pressure testing is a print-process screen, not a service condition. In the appliance the reservoir is vented. The pressure ladder exists to expose under-fused walls, weak seams, and bad boss geometry before syrup ever goes into the part.

### 1. Coupon And Boss Tests

Print small artifacts before printing a tank:

- Flat wall coupon with the intended wall schedule.
- Corner coupon with the intended internal radius.
- Outlet boss coupon with the intended fitting/seal stack.
- Vent boss coupon with the intended filter holder geometry.
- Weld-line / seam coupon using the same orientation expected on the reservoir.

Checks:

- Weigh dry.
- Fill or submerge with dyed water for 24 hours.
- Pressurize gently from the wet side and inspect for weep paths.
- Run a pressure ladder on water-filled coupons: 5, 15, 30, 60, then 100 PSI if the earlier steps are boring. Hold each step for 10 minutes and inspect before moving up.
- Dry exterior, weigh again, and note any mass gain.
- Cut at least one coupon open and inspect wall fusion under magnification.

Pass condition: no visible weeping, no dye path through corners or bosses, no pressure-step bubble trail, and no obvious under-fused internal void chain.

### 2. Mini Reservoir

Print a 100-250 mL reservoir that uses the same wall schedule, vent boss, outlet sump, and fitting geometry as the full part.

Water tests:

- Fill with dyed water and hold upright for 24 hours.
- Hold on each side and inverted for 24 hours per orientation.
- Plug the vent and outlet, then run a low-pressure submerged bubble test.
- If the bubble test is clean, repeat the coupon pressure ladder on the mini reservoir before printing the full-volume part.
- Pull from the outlet with the actual peristaltic pump and confirm flow does not become vacuum-limited when the vent is active.
- Fill through the intended fill port and confirm the vent clears displaced air without burping liquid.

Cleaning tests:

- Run water in, water out.
- Run air in, air out.
- Repeat until the outlet runs visibly clear after dyed water.
- Open the test reservoir and inspect the outlet sump, vent standpipe, and corners.

Pass condition: no liquid escape except through intended ports, no pump starvation with the vent installed, no trapped dyed water after the clean cycle.

### 3. Full-Volume Water Reservoir

Print the first approximately 1 L reservoir using the same settings that passed the mini reservoir.

Checks:

- 48-hour dyed-water hold in normal installed orientation.
- 24-hour hold at each credible shipping/service orientation.
- Refrigerator-temperature soak at 2-8°C for 48 hours.
- Five fill/dispense/clean cycles using the manifold path.
- Pump dosing comparison against a known-good Platypus bladder at the same syrup-equivalent viscosity.

Pass condition: no weeping, no dosing drift attributable to vent restriction or reservoir geometry, no retained rinse water that would dilute the next fill.

### 4. Syrup Dwell

Use actual SodaStream-compatible concentrate only after water behavior is boring.

Checks:

- 7-day cold dwell with Diet Mountain Dew syrup or equivalent acidic concentrate.
- Daily exterior wipe check for tackiness or syrup odor.
- Dispense a measured volume each day and compare pump time to delivered mass.
- Run the normal clean cycle after the dwell and inspect for color/smell retention.

Pass condition: reservoir stays dry outside, pump delivery stays repeatable, and the clean cycle leaves no obvious syrup hold-up.

## Promotion Criteria

Printed hard reservoirs move from Plan B toward the main architecture only after:

- Two different reservoir prints pass the full water sequence.
- At least one print passes the syrup dwell sequence.
- The vent/filter geometry survives fill, dispense, and clean cycles without becoming the flow limiter.
- The part fits the cold-core packaging better than the Platypus-shell design by enough margin to matter.

Until then, Platypus bladders remain the known-good fallback because they already work in the prototype.

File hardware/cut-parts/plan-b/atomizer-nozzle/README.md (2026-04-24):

# Atomizer Nozzle — 316L SS Two-Piece Pressure-Swirl

Custom hollow-cone pressure-swirl atomizer for the carbonator vessel
water-refill spray.  Designed for Xometry CNC production in 316L SS as
an alternative to off-shelf BETE / Lechler nozzles that are quote-only
or require phone orders.

## Parts

| File | Description |
|---|---|
| `atomizer-nozzle-body.step` | Nozzle body (1/2" hex, 1/8"-27 NPT male outlet, 1/4"-28 UNF inlet) |
| `atomizer-nozzle-puck.step` | Swirl distributor insert (press fit into body) |
| `atomizer-nozzle-body-drawing.pdf` | ANSI A drawing: section A—A + outlet face view, tolerance callouts |
| `atomizer-nozzle-puck-drawing.pdf` | ANSI A drawing: front face + side section, slot/feed-hole callouts |
| `generate_step_cadquery.py` | CadQuery source that produces both STEPs |
| `generate_drawing.py` | ReportLab source that produces both PDFs |

To regenerate:
```
tools/cad-venv/bin/python hardware/cut-parts/atomizer-nozzle/generate_step_cadquery.py
tools/cad-venv/bin/python hardware/cut-parts/atomizer-nozzle/generate_drawing.py
```

## Operating point

Sized to match **BETE CW25-H** (catalog hollow-cone atomizer that hits
exactly our spec):

| Parameter | Target | Notes |
|---|---|---|
| Inlet pressure | ~100 psi | Seaflo diaphragm pump |
| Vessel backpressure | 60–70 psi | CO₂ headspace |
| ΔP across nozzle | 30–40 psi | Design point |
| Flow rate | ~0.20 GPM (0.76 L/min) | At design ΔP |
| Spray pattern | Hollow cone | For maximum droplet surface area in CO₂ headspace |
| Cone angle | ~65–75° included | Per Rizk/Lefebvre K-curve at our geometry |
| Droplet size | ~100–150 µm MMD | Lefebvre SMD correlation |

## Critical dimensions

| Feature | Value | Tol. | Source |
|---|---|---|---|
| Orifice diameter | Ø1.10 mm | ±0.025 | BETE CW25-H |
| Orifice land length | 0.70 mm | ±0.05 | L/D = 0.64 (Lefebvre 0.5–1.0) |
| Swirl chamber D | Ø4.00 mm | H7 | D_s/d_o = 3.6 (Rizk 3–5) |
| Swirl chamber L (body) | 3.00 mm | ±0.10 | L_s/D_s = 0.75 |
| Convergent cone | 90° incl. | ±2° | Rusak 2020 ("manufacturable") |
| Puck OD / body seat | Ø6.00 | h7 / H7 | Light press, 0.005–0.010 mm interference |
| Puck length | 2.50 mm | ±0.10 | — |
| Puck central bore | Ø4.00 | H7 | Air-core extension of swirl chamber |
| Tangential slots | 4× (0.50 × 0.40) mm | ±0.05 | Rusak 2020 optimized |
| Slot tangent line | 2.00 mm off-axis | ±0.02 | Fully tangential to Ø4.00 |
| Axial feed holes | 4× Ø0.50 through | ±0.025 | At r=2.50 mm (slot midline) |
| Hex outer | 12.7 mm AF | std | 1/2" wrench |
| NPT outlet | 1/8"-27 NPT male | — | Tap per NPT spec after CNC |
| Inlet bore | Ø6.40 × 8 mm | — | Tap 1/4"-28 UNF after CNC, or use push-in fitting |

## Tolerance / Xometry callouts

Only two features in this part have tight tolerances that affect
performance.  Everything else is loose and can run at shop standard.

### Critical — must enforce on drawing

1. **Orifice (Ø1.10 × 0.70 mm):**
   > "Ø1.10 ± 0.025 mm, drilled + reamed, sharp-edged inlet,
   > NO DEBURR on outlet face, concentric to cone ±0.02 mm TIR."

   Rationale: the orifice edge sharpness controls discharge coefficient
   and cone angle.  Any radius on the outlet face collapses the hollow
   cone to a full cone or solid stream.

2. **Swirl chamber to orifice concentricity:**
   > "Ø4.00 H7 swirl chamber concentric to Ø1.10 orifice within
   > 0.05 mm TIR."

   Rationale: non-concentric swirl chamber skews the cone asymmetrically.

### Secondary — shop-standard tolerances fine

- Slot depth 0.40 ±0.05, width 0.50 ±0.05 (mill with Ø0.40 end mill)
- Puck OD / body bore press fit: Ø6.00 h7 × Ø6.00 H7
- 90° convergent cone ±2°
- Feed hole Ø0.50 ±0.025

### Loose — no call-out needed

- Hex outer dimensions (wrench size is the only constraint)
- NPT thread dimensions (standard tap)
- Overall length, inlet bore depth

## Xometry order notes

- **Material:** 316L SS on both parts.  316L over 316 for better
  corrosion resistance under carbonic acid + intermittent wet/dry.
- **Surface finish:** "As machined" (Ra 3.2 µm / 125 µin).  No
  post-processing needed for food contact at this pressure.
- **Quantity:** Order qty 2–3 per part for a first iteration (room
  for assembly trial-and-error and to have spares).
- **Threading:** Xometry supports 1/8-27 NPT male and 1/4-28 UNF
  female as standard tapping options.  Select both during
  quote configuration — do NOT expect the STEP to show helical
  thread form.
- **Drawing:** Xometry's instant quote will auto-detect features,
  but the orifice and concentricity call-outs above should be
  added as a PDF drawing attachment to the quote for the features
  that matter.

## Assembly sequence

1. Inspect both parts (especially the orifice — check for burrs,
   ovality, concentricity with a bore scope).
2. Align puck front face (slot side) toward the body shoulder.
3. Start puck into the Ø6.00 H7 body bore from the inlet end.
4. Press puck home with a vise and soft-jaw arbor (or a plastic
   mandrel) until its front face bottoms out against the body's
   Ø4.00 shoulder.  The puck is then captive — cannot be removed
   non-destructively.
5. Tap 1/8-27 NPT threads in the outlet (if not done by Xometry).
6. Tap 1/4-28 UNF threads in the inlet (if not done by Xometry) or
   install a push-in fitting.
7. Bench test on the Seaflo pump:  verify spray cone angle, flow
   rate, and absence of asymmetric spray.  Target: 0.20 GPM at
   40 psi ΔP, hollow cone 65–75° included.

## Design flow path

```
   INLET (1/4"-28 UNF)
     │
     ▼
   Ø6.40 inlet bore
     │
     ▼   (puck sits here, press fit)
   Ø6.00 puck seat  ───  PUCK back face
                    ───  4× Ø0.50 feed holes axial through puck
                    ───  PUCK front face (4× tangential slots)
     │                          ↑ slots direct flow tangent to Ø4
     ▼
   Ø4.00 swirl chamber  (water enters tangentially from slots,
                         spirals down, air core forms on axis)
     │
     ▼
   90° convergent cone  (swirl chamber Ø4 → orifice Ø1.1)
     │
     ▼
   Ø1.10 × 0.70 orifice  (sharp-edged inlet, burr-free outlet)
     │
     ▼
   OUTLET (1/8"-27 NPT)  → hollow cone spray into carbonator
                           vessel headspace
```

## Iteration notes

This is **v1**.  Likely first-pass tuning variables if the first build
misses the target:

- **Cone angle too narrow** (< 60°):  Increase slot cross-section
  to raise K = A_p/(D_s·d_o).  Current K = 0.182 → cone ~65–70°.
  Target K = 0.30 → 0.60 × 0.50 slots → cone ~75°.  Edit `SLOT_W`
  and `SLOT_D` in `generate_step_cadquery.py` and regenerate.

- **Flow rate too low:**  Increase orifice diameter in small
  increments (Ø1.10 → Ø1.20).  Flow scales as d_o² × √ΔP.
  Edit `ORIFICE_D`.

- **Cone collapses to full cone or solid stream:**  Usually an
  orifice edge problem (rounded by deburr) rather than a design
  problem.  Re-quote with explicit "no deburr on outlet face".

- **Asymmetric spray:**  Swirl chamber / orifice concentricity
  defect.  Re-quote with tighter TIR call-out or move to EDM'd
  orifice.

## Sources

- BETE CW metric catalog, BETE_CW_hollowcone-metric.pdf (CW25-H row)
- Lefebvre & McDonell, *Atomization and Sprays*, 2nd ed., Routledge
  2017, Ch. 6 (simplex pressure-swirl atomizer design equations)
- Rizk & Lefebvre 1985, "Internal Flow Characteristics of Simplex
  Swirl Atomizers," AIAA J. Propulsion 1(3):193–199
- Rusak et al. 2020, "Improved Atomization via a Mechanical
  Atomizer…," PMC 7345477 (optimized simplex geometry at
  small-orifice scale, source of 0.5×0.4 slot dimensions and
  90° cone angle)
- Chaudhari, Kulshreshtha, Channiwala 2013, IJAET 5(2):76–84 —
  full worked simplex design example

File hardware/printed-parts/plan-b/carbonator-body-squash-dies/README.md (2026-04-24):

# Carbonator Body Squash Dies

3D-printed die set for crushing a round 304 SS tube into the racetrack cross-section carbonator body in a single 12-ton press stroke.

## What this does

A two-piece external die set (upper = ram side, lower = bed side), each with a half-racetrack cavity cut into its parting face. The starting workpiece is a 5.000" OD x 0.065" wall x 6.000" long 304 SS round tube. With the tube laid into the lower cavity and the upper die lowered onto it, a press stroke closes the two halves until their parting planes meet at Z=0; the tube is plastically deformed into the combined racetrack OD cavity (5.600" x 4.000"). No butt welds are needed on the body — the result is a seamless pressure vessel ready for end-cap welding.

## Why tube-squash vs D-halves (alternate path)

The primary fabrication path in this repo is `carbonator-body-press-dies/` — form two flat-sheet D-halves and butt-weld them along both flat edges. The tube-squash path, specified here, is an alternate:

| | D-half press dies | Tube-squash dies (this folder) |
|---|---|---|
| Starting material | Flat 0.048" 304 SS sheet blanks | 5" OD x 0.065" wall x 6" round tube |
| Stock cost | ~$15 for two blanks (SendCutSend) | ~$40 per tube (McMaster, ~$80/ft) |
| Number of welds on body | 2 long butt welds (both flats, 6" each) | 0 |
| Wall thickness | 0.048" (sheet) | 0.065" (smallest std. catalog wall on 5" OD) |
| Hoop-stress safety factor at 70 PSI | 4.9x | 6.6x |
| Internal support during forming | Not needed (male punch is the mandrel) | Required — flats will oil-can without it |
| Press force | 1-3 tons | Somewhat higher but still well within 12 tons |
| Main risk | Weld quality / leaks on butt seams | Wrinkling, uneven squash, flat oil-canning |

Tube-squash wins on leak surface (no longitudinal welds), loses on material cost and forming complexity.

Note: the 0.065" wall is a real design change vs the 0.048"-wall D-half plan. Since 0.065" is the smallest standard catalog wall on 5" OD round tube stock, the body OD grows slightly — OD semicircle R goes from 1.983" to 2.000", overall OD from 5.566" x 3.966" to 5.600" x 4.000". The body ID at the curved end is unchanged at R = 1.935", so **end-cap DXFs from the primary path are reusable without modification**.

## Sourcing the tube

Commercial-grade 304 SS round tube, 5.000" OD x 0.065" wall x 6.000" long (or longer and cut to length). Welded tube is fine — food-grade inside finish is nice but not required; the end-caps and flavor injection happen downstream. Mill finish or 2B outside is fine.

- McMaster-Carr 89955K85 or similar (welded 304, 5" OD, 0.065" wall) — price-check before ordering; tube stock pricing moves.
- Onlinemetals / MetalsDepot have comparable SKUs.

Cut to 6.000" +0.030 / -0 with a cold saw or portaband; deburr ID and OD. The axial length is non-critical — end-caps slip-fit into the ID and are welded at the ID/OD corner, so an extra 0.030" of length just gets trimmed off at final assembly.

## Starting vs final dimensions

| Dimension | Starting tube (round) | Final body (racetrack) |
|---|---|---|
| Length along tube axis (Y) | 6.000" | 6.000" |
| Bounding box (X x Z) | 5.000" x 5.000" | 5.600" x 4.000" |
| OD semicircle radius | R = 2.500" (full circle) | R = 2.000" at each end |
| OD flat length (X) | n/a | 1.600" top + 1.600" bottom |
| ID semicircle radius | R = 2.435" | R = 1.935" at each end |
| ID flat length (X) | n/a | 1.600" top + 1.600" bottom |
| Wall thickness | 0.065" | 0.065" (minor thinning at flat-to-semi transitions) |

The racetrack OD cross-section (major axis along X, minor along Z):

```
            X (long axis)
  <----------- 5.600" ----------->
    ___________________________
   /                           \   ^
  /                             \  |
 |          top flat             | |
 |      (1.600" across, X)       | |
 |                               | 4.000"  Z (press axis)
 |       bottom flat             | |
  \                             /  |
   \___________________________/   v
```

Two semicircles (R = 2.000") at each end, joined by two straight flats (length 1.600", one at Z = +2.000" and one at Z = -2.000").

## Internal support — design decision

The tube flats (1.600" span x 0.065" wall x 6" long) will oil-can inward during pressing without something inside the tube pushing back. Three strategies:

### 1. Sand-pack (primary — recommended)

Plug one end of the tube (rubber cap, tape, whatever), fill with fine dry silica sand (play sand, #70-100 mesh, dry), tamp/tap to settle, plug the other end. Press. Remove plugs, pour sand out, re-use. Traditional pipefitter technique for bending thin-wall tube without kinks. The sand column is nearly incompressible in bulk — it supports the flats against inward collapse while still allowing the cross-section to deform into the racetrack shape because the sand flows plastically to redistribute.

**Why this is the primary path:** zero printed-part complexity, cheap, infinitely reusable, no mandrel extraction problem.

### 2. Splittable multi-piece mandrel (alternate, not designed here)

A racetrack-shaped mandrel placed inside the tube before pressing. The racetrack mandrel cross-section has a 5.470" x 3.870" bounding box — diagonal 5.473" — which exceeds the round tube ID of 4.870". So the mandrel cannot be inserted axially as one piece; it would have to assemble inside the tube from 3+ axial segments, or split longitudinally and spread. Designable but fussy. Not generated in this directory.

### 3. Two-stage forming with mid-stage mandrel insertion (alternate, not designed here)

Partial-press the round tube to an oval with its long axis >= 5.470" (clearing the racetrack mandrel diagonal), open the press, slide a single-piece racetrack mandrel in from one end, finish-press. Requires a pair of intermediate-stage dies and careful stroke control. Not generated.

If sand-pack produces unacceptable flat bulging in v1, re-evaluate option 3 first (one-piece mandrel is simpler than a segmented one); option 2 is the last resort.

## Die architecture

### Upper die (ram side) — concave upper-half cavity

A solid rectangular block with the upper half of the racetrack OD cavity cut into its lower (parting) face, extruded along the tube axis (Y). The block sits above the parting plane Z=0 and extends upward to Z = +2.500". The cavity removes material from Z=0 down to the flat at Z = +2.000" plus the two upper semicircle halves at (X = +/-0.800, Z=0).

- Cavity cross-section: two quarter-arcs of R = 2.000" centered at (X=+/-0.800, Z=0), connecting the parting-plane points (X=+/-2.800, Z=0) up to the flat-tangent points (X=+/-0.800, Z=+2.000"); a straight flat at Z = +2.000" from X = -0.800 to X = +0.800
- Cavity half-depth: 2.000" (Z=0 to Z=+2.000")
- Wall: 0.500" around the cavity perimeter on all four sides (matches body-press-dies convention)
- Floor above cavity: 0.500" for press-ram contact
- Block height: 2.000" (cavity) + 0.500" (floor) = 2.500"
- Block footprint: (5.600 + 2 * 0.500) x (6.000 + 2 * 0.500) = 6.600" x 7.000"

### Lower die (bed side) — concave lower-half cavity

Mirror image of the upper die. Block sits below Z=0 down to Z = -2.500". Cavity is the lower half of the racetrack OD (quarter-arcs at the ends, flat at Z = -2.000").

Footprint matches the upper — 6.600" x 7.000".

### Closed stack

When the press closes and the two parting faces kiss at Z=0, the combined cavity is the full racetrack OD (5.600" X x 4.000" Z x 6.000" Y), and the overall stack height is 5.000" (2 x 2.500").

### Registration

Two dowel pin holes (0.250" dia, 0.375" deep) per die half, on the long-axis centerline (X = 0), flanking the cavity in Y at +/- 3.250". The holes drill downward from the upper die's parting face and upward from the lower die's parting face so they align when the halves close. Same approach and offsets as the D-half body-press-dies and the dishing dies.

## Material

- PA6-CF, 100% infill
- Printer: Bambu H2C (300 x 320 x 325 mm build volume)
- Estimated mass per half: see the generator's diagnostics block output. Target <= 1500 g per half.

Each block fits inside the H2C's build volume and inside a 12-ton H-frame press's typical throat clearance.

## Forming notes

- **Sequence:** cut tube to length, deburr, plug one end, fill with dry sand, tamp, plug other end. Lube OD. Lay tube into lower die cavity centered on Y. Lower upper die by hand until it contacts the tube. Check visually that it's seated straight, not skewed. Apply press force slowly — 1 ton, pause, inspect; 3 tons, pause; close fully. Hold briefly, release. Remove upper die, unplug tube, pour sand, tap out residue.
- **Force:** D-half forming was estimated at 1-3 tons; squashing a thicker-wall tube with sand-pack inside is somewhat higher (sand load transfer adds resistance), but comfortably within the 12-ton VEVOR press. Go slow regardless and listen for any cracking or popping.
- **Springback:** the minor-axis flats will want to re-bulge outward after the press opens. The script exposes a `SPRINGBACK_COMP` constant (default `0.0`) that shrinks the cavity Z depth by the given fractional amount — so the die over-squashes the tube in Z, and the elastic recovery springs it back to 4.000". The X dimension is governed by the semicircle diameter, which is mechanically pinned by the tube's circumference, so X is left un-compensated. Measure the first squashed body against the end-cap slip-fit (R = 1.930" tube ID target at the curved ends, and 4.000" overall Z). If the minor axis measures oversize (flats bulged back out), bump `SPRINGBACK_COMP` to 0.02-0.04 and reprint. Typical 304 SS springback in this geometry is 2-4%.
- **Lubrication:** dry-film or wax on the tube OD and the cavity surfaces. Lube matters here — the tube has to slide radially inward against the cavity walls as it deforms.
- **Sacrifice the first tube.** At ~$40 per blank, burn the first one for calibration: sand-pack quality, squash sequence, springback value. Measure the result, tune `SPRINGBACK_COMP` if needed, reprint dies, then squash the "real" tube.
- **After pressing:** inspect flats for oil-canning and the semicircles for out-of-round at the ends. If one end is worse than the other (often the plug-fill end — sand didn't pack as tightly there), try tamping harder next time. Deburr cut ends, check that end-caps slip-fit (R = 1.930" against the formed ID curves), then weld end-caps.

## Files to generate

- `generate_step_cadquery.py` — parametric CadQuery script producing STEP files for both die halves
- Run with `tools/cad-venv/bin/python`
- Outputs `body-squash-die-upper.step` and `body-squash-die-lower.step` in this directory

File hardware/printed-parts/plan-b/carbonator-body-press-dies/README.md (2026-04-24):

# Carbonator Body Press Dies

3D-printed die set for press-forming flat 0.048" 304 SS blanks into D-shaped halves of the racetrack-cross-section carbonator tube body.

## What this does

A two-piece die (concave female on bottom, convex male on top) wrap-bends a flat sheet blank around a D-shaped punch into a matching D-shaped cavity. The resulting D-half is half of the full racetrack tube cross-section, split along the racetrack's minor (short) axis. Two D-halves butt-weld together along both flat edges to close the full racetrack. This approach avoids rolling a closed loop on the slip roll, which would jam in the rollers.

## Source geometry

Body sheet blanks are defined in:
`hardware/cut-parts/carbonator-body-sheet/generate_dxf.py`

Blanks are laser-cut by SendCutSend at 7.754" x 6.000" x 0.048" 304 SS annealed.

## D-half geometry

The D-half cross-section (viewed along the tube axis) is a flat-bottomed U rotated 180 degrees: two vertical tangent walls flanking a half-circle at the bottom.

Inside surface (what the male punch shapes):
  Semicircle radius: 1.935" (= tube ID at the curved end, matches end-cap slip-fit at R=1.930")
  Tangent-wall length: 0.800" per side (two per D-half)
  Tube axis length: 6.000"

Outside surface (what the female cavity shapes):
  Semicircle radius: 1.935 + 0.048 = 1.983" (tube OD at the curved end)
  Tangent walls at X = +/-1.983"

Developed flat blank length (straight-bend neutral-axis at mid-thickness):
  L = 0.800 + pi * (1.935 + 0.048/2) + 0.800
    = 0.800 + 6.154 + 0.800
    = 7.754"

## Blank and final dimensions

| Dimension | Blank (pre-forming) | Final D-half (after pressing) |
|---|---|---|
| Length along tube axis (Y) | 6.000" | 6.000" |
| Width (developed / wrapped) | 7.754" | 7.754" wrapped around D |
| Inside semicircle radius | flat | 1.935" |
| Tangent-wall height | flat | 0.800" per side |
| Thickness | 0.048" | 0.048" (minor thinning at apex) |

The butt-weld seam sits at the top of each D-half's tangent walls. When two D-halves are welded together, the result is the full racetrack tube: two semicircles of R = 1.935" (ID) connected by two flat walls each 1.600" tall (0.800" + 0.800").

## Die architecture

### Female die (bottom) — concave cavity

A solid rectangular block with a D-shaped cavity on the top face, extruded along the tube axis (Y). The blank lies flat on the top face (the "die land") before pressing. The cavity's inside surface matches the sheet's outside surface (all radii = 1.983", walls at X = +/-1.983").

- Cavity cross-section: two vertical walls at X = +/-1.983" from Z = 0 down to Z = -0.800, then a semicircle of R = 1.983" from (+1.983, -0.800) through apex (0, -2.783) to (-1.983, -0.800)
- Cavity depth: 2.783" (total Z travel from die land to apex)
- Wall: 0.500" around the cavity perimeter on all four sides (heavier than the dishing die because the cavity is much deeper and forming forces are higher)
- Floor under cavity: 0.500"
- Block height: 2.783" (cavity) + 0.500" (floor) = 3.283"
- Block footprint: (2 * 1.983 + 2 * 0.500) x (6.000 + 2 * 0.500) = 4.966" x 7.000"

### Male die (top) — convex punch

A rectangular flange/backing block with a D-shaped punch protruding from its bottom face, extruded along the tube axis (Y). The punch matches the blank's inside surface (all radii = 1.935", walls at X = +/-1.935"), so the radial gap between punch and cavity equals 0.048" = sheet thickness at every point on the D.

- Punch cross-section: two vertical walls at X = +/-1.935" from Z = 0 down to Z = -0.800, then a semicircle of R = 1.935" from (+1.935, -0.800) through apex (0, -2.735) to (-1.935, -0.800)
- Punch descent below flange: 2.735"
- Flange (blank holder): the flat surround rests on the female die's top surface during forming; it pins the blank edges so they cannot wrinkle or lift as the punch descends
- Backing plate above flange: 0.500" for press-ram contact
- Block height: 2.735" (punch) + 0.500" (backing) = 3.235"
- Block footprint: matches the female — 4.966" x 7.000"

### Registration

Two dowel pin holes (0.250" dia, 0.375" deep) per die half, on the tube-axis centerline (X = 0), flanking the cavity in Y at +/-3.250". The holes drill downward from the female's die-land face and upward from the male's flange face so they align when the halves are brought together. Same approach as the dishing dies.

## Material

- PA6-CF, 100% infill
- Printer: Bambu H2C
- Estimated mass: ~1180 g (female), ~1450 g (male), from the generator's diagnostics block. Both under the 1500 g per-half target.

Each block fits well inside the H2C's 300 x 320 x 325 mm build volume and well inside a 12-ton H-frame press's typical throat clearance.
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

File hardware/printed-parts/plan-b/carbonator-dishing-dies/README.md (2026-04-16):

# Carbonator End Cap Dishing Dies

3D-printed die set for press-doming flat 0.060" 304 SS racetrack blanks into shallow domed end caps for the carbonator vessel.

## What this does

A two-piece die (concave female on bottom, convex male on top) that presses a flat racetrack blank into a shallow spherical dome. The dome converts the stress mode from plate bending to membrane, allowing 0.060" sheet to do the work of 0.250" flat plate.

## Source geometry

End cap blanks are defined in:
`hardware/cut-parts/carbonator-endcaps-racetrack/generate_dxf.py`

## Dome geometry

The dome is a spherical cap — a single sphere radius intersected with the racetrack footprint. The sphere radius is set so the dome apex reaches 0.250" below the rim at the major axis extremes (the longest unsupported span, which drives the UG-32 calculation).

Sphere radius from the major axis half-span:
  a = 5.460 / 2 = 2.730" (final cap major half-span)
  h = 0.250" (dome height at major axis extremes)
  R = (a² + h²) / (2h) = (7.4529 + 0.0625) / 0.500 = 15.03"

Dome heights at key points:
  Major axis extremes (±2.730" from center): 0.250"
  Minor axis extremes (±1.930" from center): 0.125"
  Center of cap: 0.250" (apex)

The dome is subtle — 0.250" over a 5.5" span is barely visible. But it's enough to switch the structural mode from bending to membrane.
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

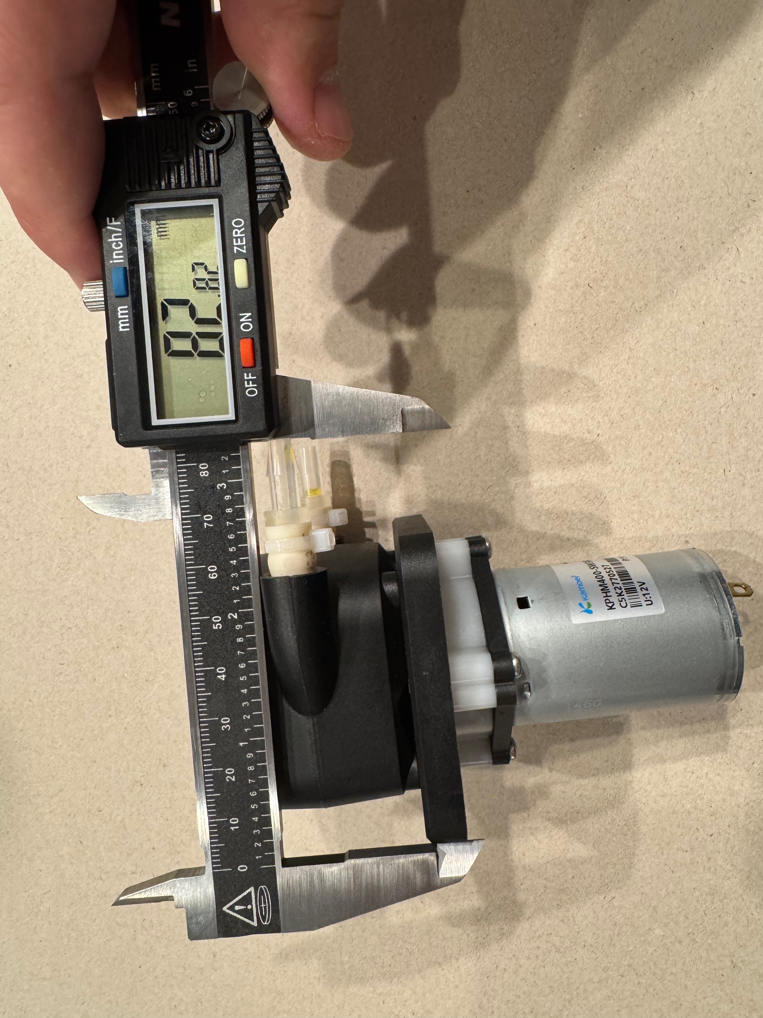
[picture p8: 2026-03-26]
hardware/off-the-shelf-parts/kamoer-kphm400/raw-images/17-pump-head-with-connectors-height-82.82mm.jpeg

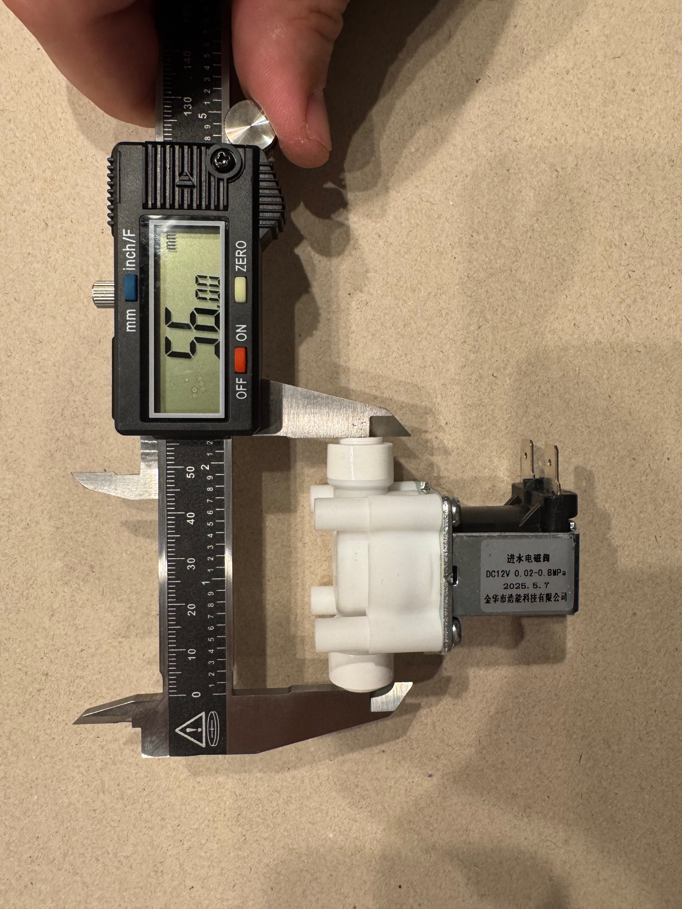
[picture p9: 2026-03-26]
hardware/off-the-shelf-parts/beduan-solenoid/raw-images/01-collet-to-collet-56.00mm.jpeg

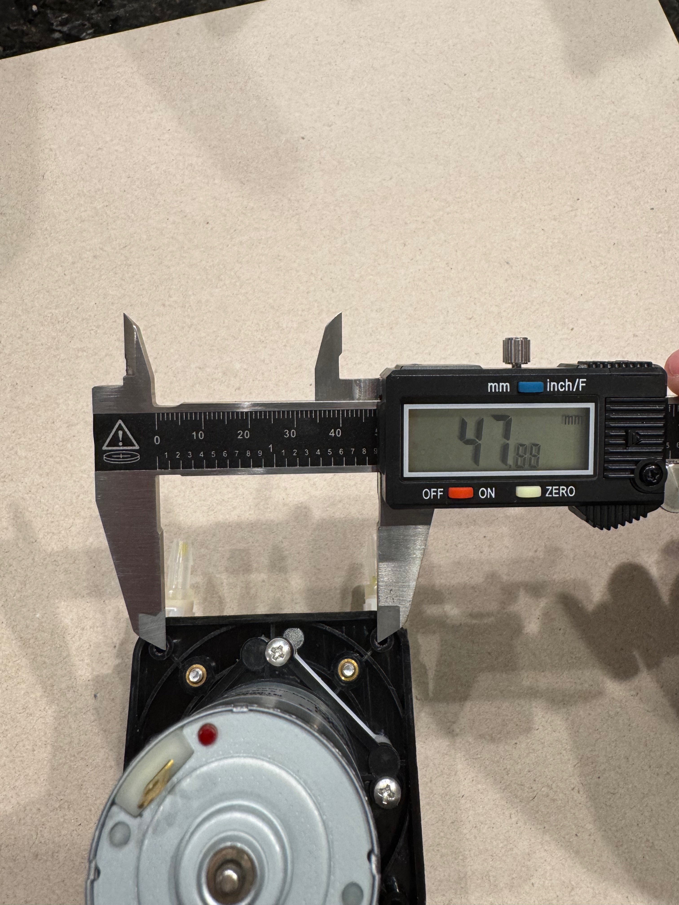
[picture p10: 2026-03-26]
hardware/off-the-shelf-parts/kamoer-kphm400/raw-images/05-mounting-hole-edge-to-edge-47.88mm.jpeg

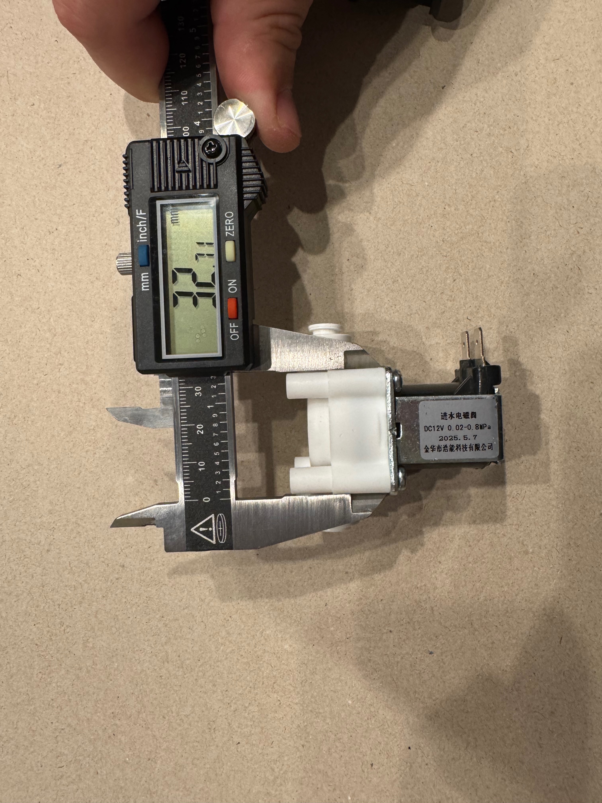
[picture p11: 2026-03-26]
hardware/off-the-shelf-parts/beduan-solenoid/raw-images/03-white-body-square-edge-to-edge-32.71mm.jpeg

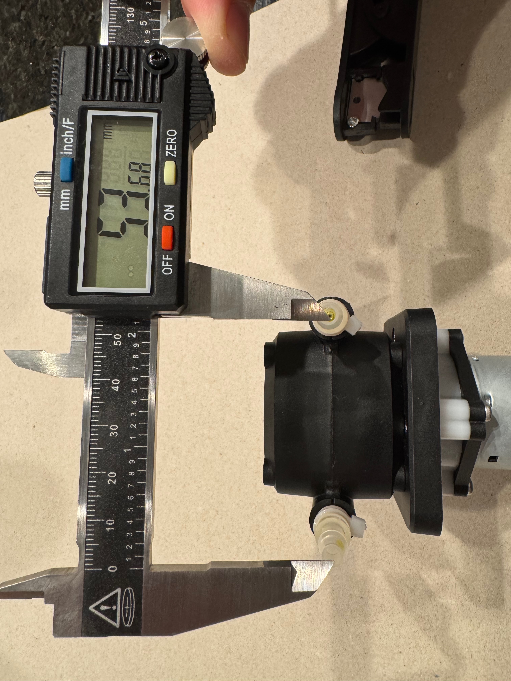
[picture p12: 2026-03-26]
hardware/off-the-shelf-parts/kamoer-kphm400/raw-images/13-pump-head-dimension-51.68mm.jpeg

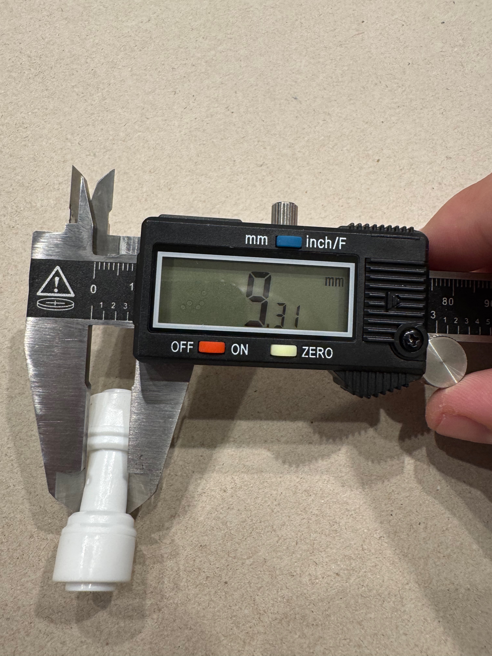
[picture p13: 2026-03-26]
hardware/off-the-shelf-parts/john-guest-union/raw-images/06-narrow-feature-9.31mm.jpeg

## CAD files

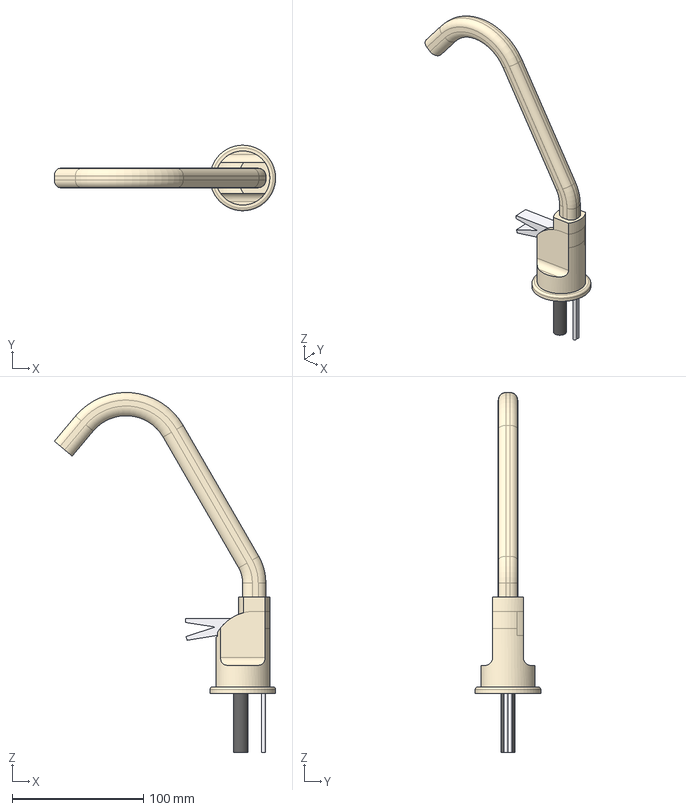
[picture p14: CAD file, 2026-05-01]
hardware/harvested/touch-flo-faucet/faucet-assembly/touch-flo-faucet-assembly.step
168.5 x 50.0 x 274.1 mm
valve_body
water_dispense_tube
flavor_tube_pos_y
flavor_tube_neg_y
lever
mounting_plate

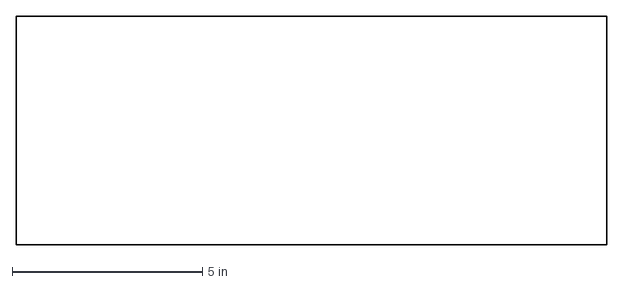
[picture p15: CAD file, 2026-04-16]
hardware/cut-parts/carbonator-body-sheet/carbonator-body-blank.dxf
15.5 x 6.00 in

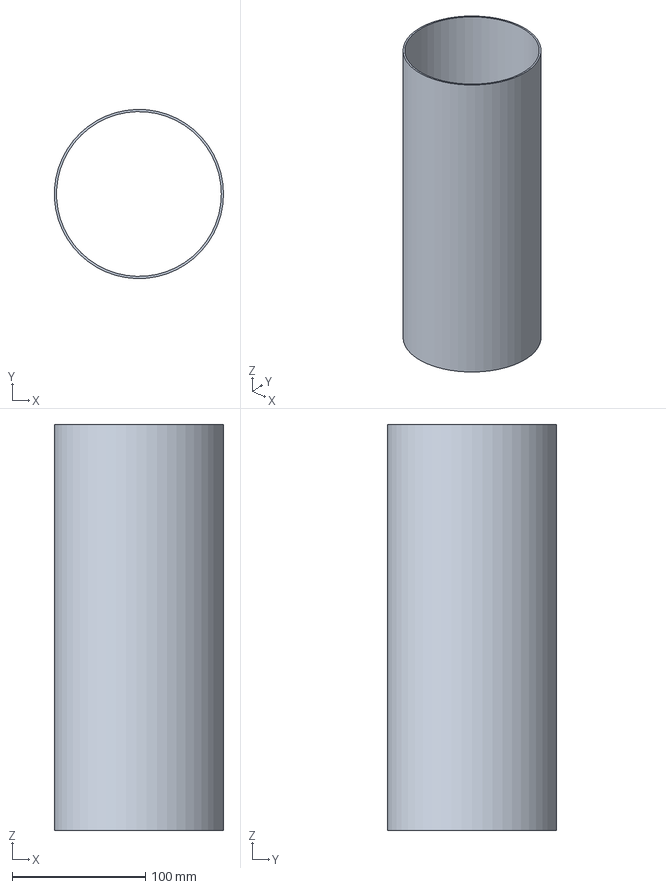
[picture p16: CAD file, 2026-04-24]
hardware/cut-parts/carbonator-body-tube/carbonator-body-tube-5od-0p065wall-12in.step
126.9 x 126.9 x 304.8 mm

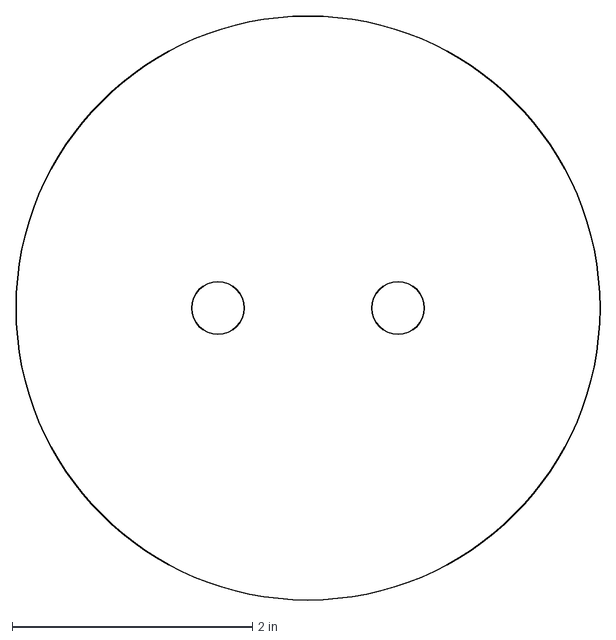
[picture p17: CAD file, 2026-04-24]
hardware/cut-parts/carbonator-endcaps-circular/endcap-circular-2hole.dxf
4.86 x 4.86 in

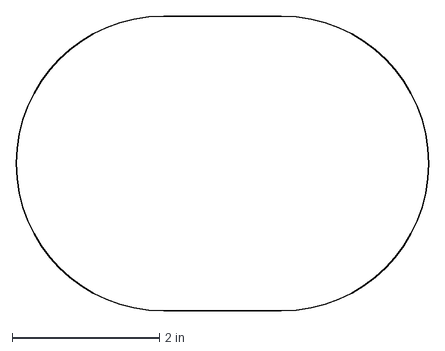
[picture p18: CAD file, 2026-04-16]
hardware/cut-parts/carbonator-endcaps-racetrack/die-profile-racetrack.dxf
5.60 x 4.00 in

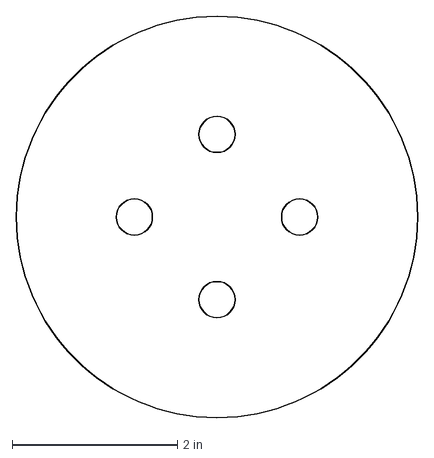
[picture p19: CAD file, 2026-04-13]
hardware/cut-parts/carbonator-endcaps/endcap-top-4hole.dxf
4.86 x 4.86 in

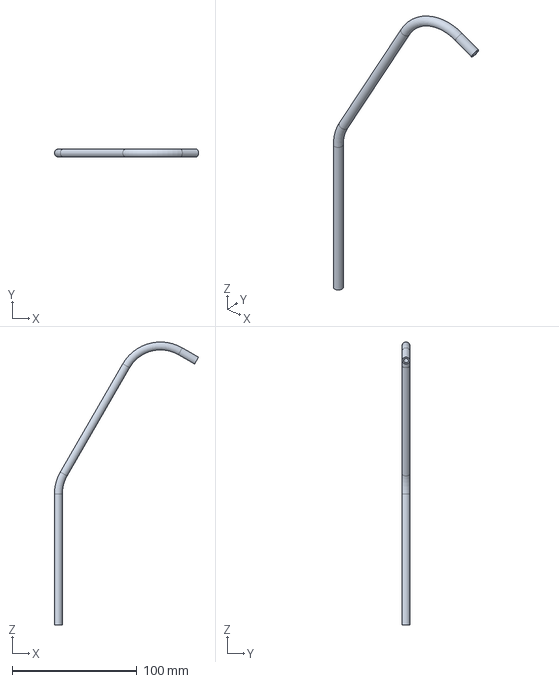
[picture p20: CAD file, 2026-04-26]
hardware/cut-parts/dispense-flavor-tube/dispense-flavor-tube-quarter-od-0p049wall.step
115.4 x 6.35 x 226.5 mm

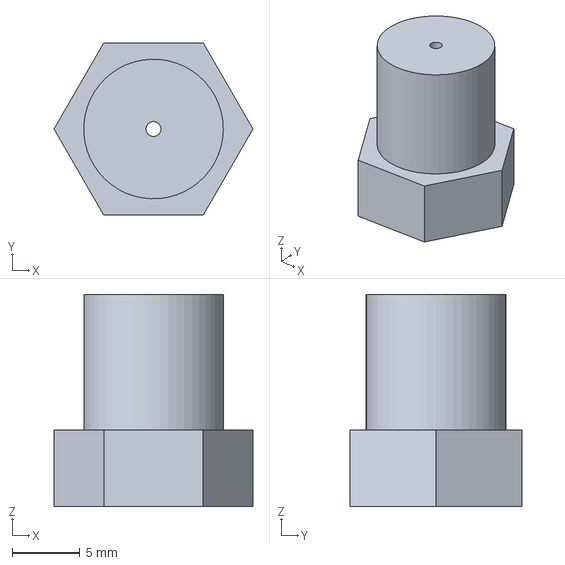
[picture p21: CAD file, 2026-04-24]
hardware/cut-parts/plan-b/atomizer-nozzle/atomizer-nozzle-body.step
14.7 x 12.7 x 15.7 mm

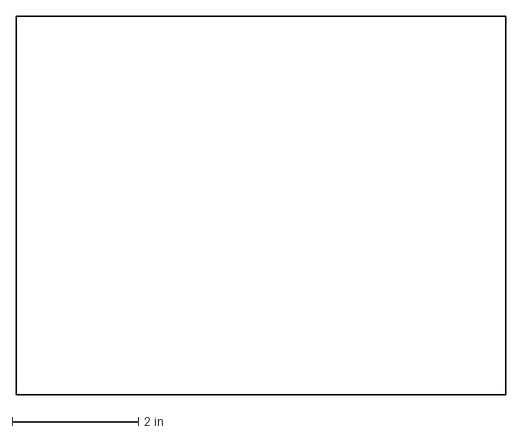
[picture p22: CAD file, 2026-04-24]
hardware/cut-parts/plan-b/carbonator-body-sheet/carbonator-body-half-blank.dxf
7.75 x 6.00 in

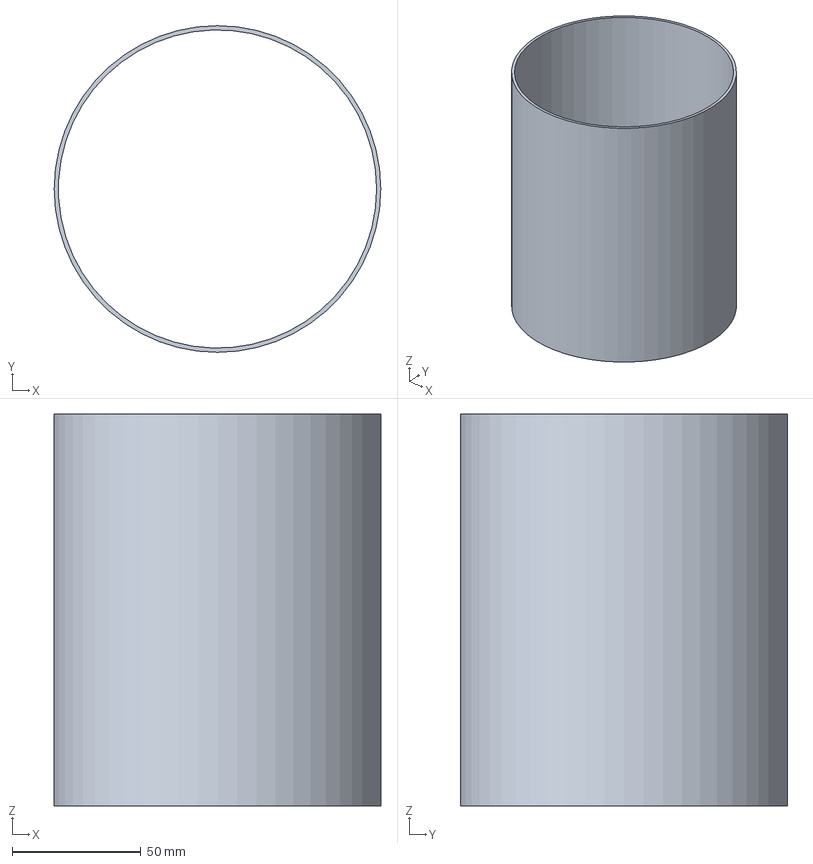
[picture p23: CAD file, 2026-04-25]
hardware/cut-parts/plan-b/carbonator-body-tube/carbonator-body-tube-5od-0p065wall-6in.step
127.0 x 127.0 x 152.4 mm

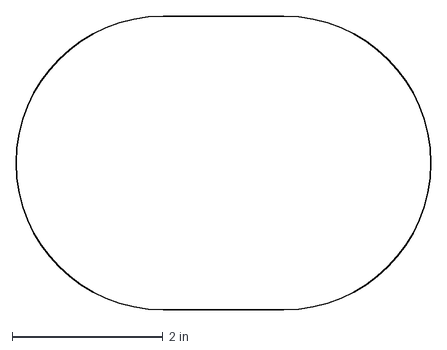
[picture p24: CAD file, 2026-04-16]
hardware/cut-parts/plan-b/carbonator-endcaps-racetrack/endcap-racetrack-bottom-blank.dxf
5.49 x 3.89 in

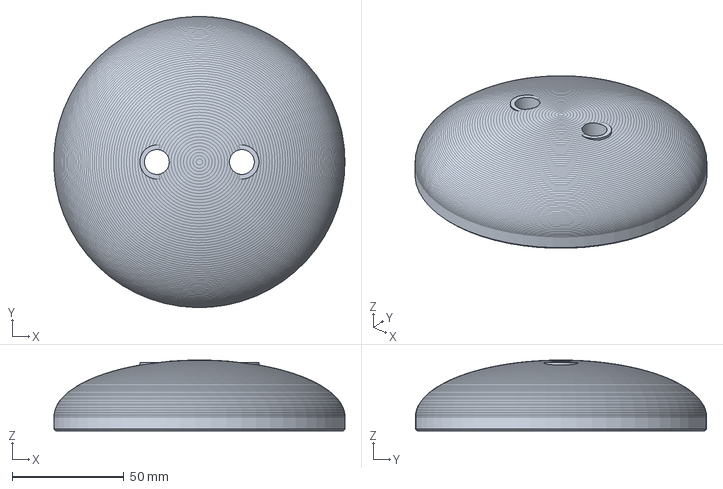
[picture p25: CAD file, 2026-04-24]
hardware/cut-parts/plan-b/carbonator-milled-dome-cap-min/carbonator-milled-dome-cap-min.step
130.3 x 130.4 x 31.8 mm

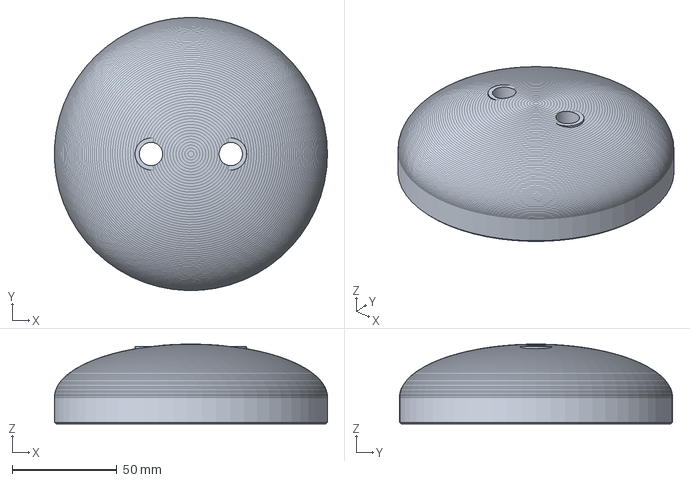
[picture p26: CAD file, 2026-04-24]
hardware/cut-parts/plan-b/carbonator-milled-dome-cap/carbonator-milled-dome-cap.step
130.3 x 130.4 x 38.1 mm

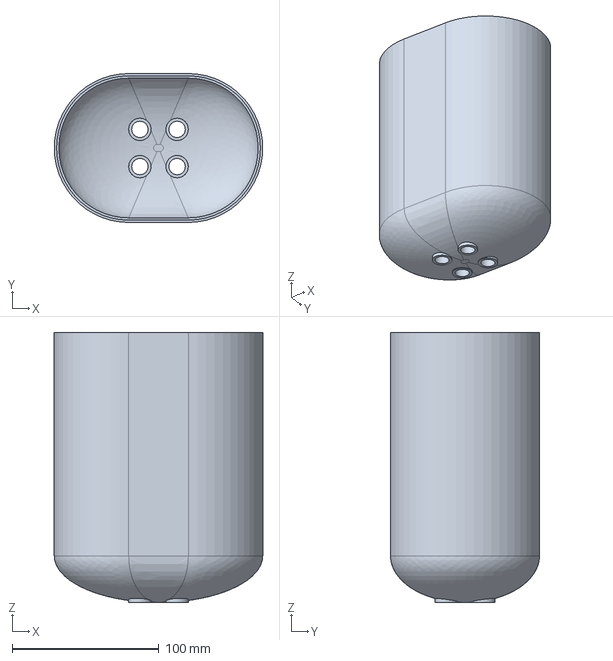
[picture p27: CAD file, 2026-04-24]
hardware/cut-parts/plan-b/carbonator-milled-pot/carbonator-milled-pot.step
142.2 x 101.6 x 184.2 mm

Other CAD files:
hardware/harvested/touch-flo-faucet/valve-body-reference/touch-flo-valve-body-reference.step
hardware/printed-parts/case-snaps/case-snaps-top-0.4mm-deflection.step
hardware/printed-parts/foam-bag-shell/copper-outlet-plug.step
hardware/printed-parts/peristaltic-tube/peristaltic-tube.step
hardware/cut-parts/carbonator-endcaps/endcap-bottom-1hole.dxf
hardware/cut-parts/carbonator-endcaps/endcap-top-3hole.dxf
hardware/cut-parts/dispense-flavor-tube/dispense-flavor-tube-quarter-od-0p035wall.step
hardware/cut-parts/plan-b/atomizer-nozzle/atomizer-nozzle-puck.step
hardware/cut-parts/plan-b/carbonator-body-tube/carbonator-body-tube-5od-0p035wall-6in.step
hardware/cut-parts/plan-b/carbonator-body-tube/carbonator-body-tube-5od-0p049wall-6in.step
hardware/cut-parts/plan-b/carbonator-endcaps-racetrack/endcap-racetrack-top.dxf
hardware/printed-parts/case-snaps/case-snaps-bottom-0.3mm-deflection.step
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

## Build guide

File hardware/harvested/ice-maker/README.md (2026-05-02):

# Ice Maker Teardowns

Two countertop ice makers were purchased for harvesting refrigeration components (compressor, condenser + fan, capillary tube, filter-drier). See `hardware/future.md` for how the harvested parts fit into the cold core assembly.

## Two architectural paths for the cold core

As of 2026-05-01, the cold core design is centered on Path A. Keep-vs-discard decisions below depend on whether Path B is revived as a fallback.

- **Path A — custom SS carbonator + new evaporator coil.** Discard the factory finger-plate evaporator; wind a custom copper coil around the fabricated 316L SS carbonator. Current `hardware/future.md` Plan A is a vertical 5" OD × 0.065" wall 316 welded round tube with 1/4"-thick 316 circular end plates. Refrigerant loop must be opened (cut into the suction and cap-tube sides of the factory evaporator), so factory charge must be vented, drier replaced, system evacuated, and recharged. This path is the one `future.md` describes.
- **Path B — factory evaporator kept in place, FDM-printed pressure vessel around it.** Keep the factory finger-plate evaporator wired in-circuit, exactly as shipped. Surround it with a PA6-CF structural shell lined with TPU (the TPU is the pressure boundary; the CF shell carries hoop stress). The refrigerant loop is never opened — factory charge stays sealed, no vent / recharge needed. The evaporator's cold fingers become the internal geometry of the vessel.

Under Path B the evaporator, the cap tube, the filter-drier, and the suction line all stay intact and move out of the "discard" column. The hot-gas bypass solenoid is still deleted (we want steady cold, not harvest cycles) under both paths.

R-600a is carved out of the EPA Section 608 venting prohibition as a natural refrigerant, so no 608 certification is legally required for either path. Standard (non-hydrocarbon-rated) HVAC vacuum pump and manifold are fine — we vent to atmosphere rather than recover, so recovery-equipment hydrocarbon compatibility is moot.

---

## Unit A — Generic countertop, 8 cubes / 6 min

- ASIN: **B0F42MT8JX**
- Price: $63.80
- Rated output: 26 lb/day
- First teardown: 2026-04-17

### Refrigerant

**R600a (isobutane).** Flammable. Charge is small (well under the 150 g UL 60335-2-89 limit for small appliances; factory label will list the exact mass). Brazing anywhere in the sealed loop requires the charge to be vented first — do not heat a pressurized R600a circuit.

### Refrigerant circuit topology (verified by disassembly)

```
    ┌── discharge ──► condenser ──► filter-drier ──► capillary tube ──┐
    │                                                     (bonded to   │
compressor                                                suction line)│
    │                                                                  ▼
    └── suction ◄──────────────────────────────── evaporator ◄─────────┘

    side branch:  compressor discharge ──► hot-gas bypass solenoid ──► evaporator
                  (active only during harvest cycle — delete for our use)

    not in the loop: compressor process tube (factory charge port, dead-end stub)
```

This matches standard R600a small-appliance practice. Verified by tracing the tubing on this unit during teardown, not assumed from reference material.

### Compressor

- Manufacturer: NingBo Anuodan Machinery Co., Ltd
- Model: **HD48Y11**
- Hermetic reciprocating, 1-phase, thermally protected, UL / CSM listed
- Larger than intuition suggests for a $64 appliance — this is normal. R600a hermetic cans have a floor size set by the motor, piston, and oil sump regardless of rated capacity. Freezing cubes in six minutes demands real wattage; this is likely in the 90–120 W cooling-capacity range, which is plenty for holding a carbonator at service temperature.

### Condenser

Finned-tube forced-convection condenser with its own fan shroud (fan not yet separated in photos). Standard wire-and-plate construction. Reuse as-is — orient for front-of-enclosure mounting per the enclosure layout in `future.md`.

### Filter-drier

A fat copper cylinder sits between the condenser outlet and the capillary tube inlet. It holds a molecular-sieve desiccant charge that traps residual moisture and debris — moisture in an R600a system freezes at the capillary tube orifice and causes intermittent loss of cooling, so the drier is load-bearing for reliability, not optional.

Label on this unit's drier:

- `8.05.08.044` (leading digit ambiguous — could be `0`)
- `60-130-05` — almost certainly the drier's model / part number. Useful if sourcing a drop-in replacement from the same supply chain; not confidently decodable without the manufacturer.
- `20251107 A-1` — manufacturing date code, 2025-11-07, line/shift A-1.
- Small stylized logo at left (manufacturer mark, not identified).

**Desiccant replacement rule:** once the refrigerant loop is opened (unbrazing for re-piping), the drier's desiccant has absorbed atmospheric moisture and is spent. Replace the drier before recharging. This is standard practice, not optional — reusing a saturated drier gives a short service life and eventual capillary icing.

### Capillary tube + suction-line heat exchanger

Downstream of the filter-drier, the metering device is a hair-bore **capillary tube** (not a TXV — cheaper, no moving parts, fine for fixed-load systems like ours). ID is roughly 0.03″ (well under 1 mm) — visibly thinner than you'd think anything could flow through, and that is the entire point. This single tube drops pressure from condenser side (~100 PSI) to evaporator side (~5–10 PSI for R600a) across its length. Mass flow for a 100 W-class system is a fraction of a gram per second, so the tiny bore passes the full charge just fine.

Physical path through this unit, start to finish:

1. **Exits the filter-drier** (cap tube is brazed into the drier's outlet end).
2. **Runs bonded alongside the suction line** for most of its length — this is the passive internal heat exchanger. Cold return gas from the evaporator subcools the liquid refrigerant before it flashes, increasing effective capacity at zero cost.
3. **Coils up in a short helix** right before the evaporator inlet — packaging, to fit the required length into a small area and manage any final pressure trim.
4. **Enters the evaporator.**

Keep the bonded cap-tube-plus-suction-line pair intact when re-piping — separating them hurts efficiency for zero benefit. The helical coil at the evaporator end is also worth preserving as-is; if total cap length changes (e.g., the evaporator is relocated when we swap the cold plate for our carbonator coil), a refrigeration tech recalculates cap length for the new load, rather than guessing.

### Process tube (the "dead-end" copper stub)

A short (~2″) copper tube closed with a pinched-and-brazed tip **sticks straight out of the compressor body** and connects to nothing else — it is genuinely a dead end. This is the factory charging port. The process is: evacuate the system through this tube, inject the refrigerant charge, then crimp and braze the tip shut. It has no flow during operation. This is where recovery and recharge will tap in during reassembly — either by cutting the crimped tip and brazing on a piercing saddle / access port, or by installing a bolt-on Schrader saddle over the tube.

Do not confuse with the capillary tube. Process tube = fat short stub on the compressor, pinched shut, goes nowhere. Capillary tube = long hair-thin line threading through the main loop between filter-drier and evaporator.

### Hot-gas bypass solenoid (DISCARD for our use)

A small AC solenoid valve is teed into the refrigerant circuit:

- Label: **SOLENOID VALVE — AC 110V 50/60Hz 4/4.5 W — TIANHAQ 25.10.17**
- Function in ice maker: during the harvest cycle, this valve opens and routes hot compressor discharge gas directly into the evaporator (bypassing the condenser and capillary tube), warming the cold fingers so formed cubes release and drop. Without it, an ice maker has no way to get cubes off the evaporator.
- Function in our build: **none.** We want continuous steady cold around the carbonator, not a harvest cycle. Remove the valve entirely when re-piping, or (if it's more convenient to leave physically in place) never energize it and verify the bypass path is sealed.

### Evaporator cold plate

A stainless-finger cold plate, purpose-built for ice-cube formation. Disposition depends on which cold-core path wins (see top of document):

- **Path A:** cut out during re-piping; replace with custom copper coil around the SS carbonator. The suction-side connection point moves to the new coil.
- **Path B:** keep in place, wired to the factory loop; build the printed pressure vessel around the finger geometry. The cold fingers become part of the vessel's internal topology.

### Powering and control (AC wiring)

The compressor is a single-phase AC hermetic with a **combined PTC start relay + overload protector** clipped to its terminal block. External connection is **two wires (black + white) coming out of that module**, not directly from the compressor pins. Believed to be **110–120 VAC** based on US market origin and the 110 V rating on the hot-gas bypass solenoid — verify the compressor nameplate before energizing.

For bench testing, plug into standard 120 VAC through an **inline fuse** (5 A fast-blow is comfortable for expected ~1 A running + LRA inrush). A Kill-A-Watt inline lets you observe the LRA spike, steady running draw, and confirm the compressor is doing real work rather than just humming.

Safety:
- **R600a is flammable.** Do not energize after physical damage, near open flame, or if a butane smell is present near the compressor. The factory loop is sealed from the factory, so there's no leak risk during teardown *inspection* — leak risk only appears if the loop is opened for Path A work.
- **Minimum off-time of 3 minutes** between power-off and power-on is a hard rule. The high-side pressure has to bleed through the capillary tube and equalize with the low side before restart, or the motor stalls against head pressure until the overload trips. Repeated hot-restart is a textbook way to burn out a hermetic compressor.

For ESP32 control:
- **Reserved GPIO: pin 14** on the main ESP32-DevKitC-32E. Not a strap pin, not input-only, not reserved for flash/PSRAM. See `hardware/wiring/esp32-pinout.mmd` for the full pin map.
- **Switching element: Teyleten 3.3 V opto-isolated relay module** (10 A @ 250 VAC, ASIN B07XGZSYJV). ESP32 GPIO drives the input pin directly — 3.3 V coil side, opto-coupled, mechanical contact on the AC hot leg. ~$2.60/unit at 5-pack pricing. Audibly clicks, finite cycle life, but at this duty (minutes-per-cycle, 3-minute minimum off-time enforced in firmware) a 100,000-cycle relay lasts decades. The same relay model is used a second time per appliance to gate 12 V to the SeaFlo diaphragm pump (see `hardware/wiring/power.mmd` and `hardware/bom.md` §5).
- A 25 A solid-state relay (Fotek SSR-25 DA / Crydom class, zero-crossing, also opto-isolated) was the original plan but was rejected: at ~1 A running current the SSR's required heatsink and ~5× price weren't justified, and the cycle-life advantage doesn't matter when the duty cycle is already minutes-long.
- **Firmware must enforce the 3-minute minimum-off-time** as a guard — the relay will switch every loop iteration if told to, and that will destroy the compressor within days. Wrap the ON/OFF call behind a "can I switch right now?" check against the last-transition timestamp. A hysteresis band around the temperature setpoint (e.g., ±1 °C) is needed for the same reason — you want long cycles, not rapid thrash.

### Summary — keep vs discard for this unit

| Part | Disposition |
|---|---|
| Compressor | Keep |
| Condenser + fan | Keep |
| Capillary tube (bonded to suction line) | Keep — do not separate |
| Filter-drier | Keep in place; replace with fresh drier before recharge if the loop is opened |
| Process tube | Keep — vent/recharge access point |
| Hot-gas bypass solenoid | Discard / bypass |
| Evaporator finger plate | Path A: discard. Path B: keep in place as the vessel internal geometry |
| Thermostat / harvest-cycle controller | Discard (custom ESP32-S3 firmware replaces it) |

### Open items

- Factory refrigerant charge mass (read from the nameplate once fully exposed)
- Compressor rated cooling capacity in W — confirm against expected load of holding ~1.5 L of carbonated water at 2 °C against cabinet-ambient
- Physical dimensions of compressor + condenser pair, for enclosure layout
- Decide whether to save photos to `hardware/harvested/ice-maker/unit-a-b0f42mt8jx/raw-images/` alongside this doc

---

## Unit B — Frigidaire EFIC117-SS

- ASIN: **B07PCZKG94**
- Price: $78.70
- Rated output: 26 lb/day
- Teardown: pending

To be filled in after teardown.

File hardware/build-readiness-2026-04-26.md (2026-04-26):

# Build readiness — Unit #1 — Snapshot 2026-04-26

**This is a point-in-time snapshot, not a living document.** The data here will go stale as bom.md and purchases.md evolve. As of this writing the user is more than a month out from placing the unit-#1 order and further design work may revise the BOM in the meantime. Treat this file as a reference point for re-running the same audit later — same methodology, fresh data — and for comparing against the then-current state.

## TL;DR

- **Estimated total spend to fully provision unit #1: ~$619** (plus NE tax + shipping).
  - **~$469** in single-unit items consumed 1:1 per appliance.
  - **~$150** in pack purchases that also feed future units.
- **Lead time:** most items are Amazon Prime (1–3 day delivery). No items are stuck on a long-lead vendor. The four forward-plan SKUs (Wellbom regulator, Westbrass R2031-NL-62 faucet, DIGITEN G3/8" flow sensor, PureSec Y splitter) and the zip ties pack just need a quick "do we still want this SKU vs alternate-on-hand" review before ordering — they're not pre-ordered because they were always future-plan, not because they're hard to source.

## Source-data state at snapshot time

- `bom.md` per-unit total: **$1,286.85** (state at commit `48ca800`, after rear-panel bezel-recess directive moved to future.md; reflects Tier 2 + Tier 3 amortizations and the Kamoer/L298N/VALVENTO/ANPTGHT/VEVOR fold-up corrections)
- `purchases.md` ACQUIRED hardware: **$14,472.92** / grand total: **$19,886.69** (state at commit `7e7e7b8`, after GASHER spares order)

## Methodology

Walked every line of `bom.md` §§1–12 and cross-referenced against `purchases.md` ACQUIRED / ON-ORDER inventory, with the assumption that the **bench prototype has consumed 1 unit's worth of every item that gets physically installed** (not tools, fabrication equipment, or shop bench gear). For pack-amortized items, available pack qty is reduced by 1 (prototype consumption) before checking whether unit #1 is covered.

To re-run later: spawn a `general-purpose` Claude agent with the same prompt structure used on 2026-04-26, pointing at then-current `bom.md` and `purchases.md`. Original prompt is preserved in the conversation log on that date.

## Items needing a fresh order

### Single-unit items (consumed 1:1 per appliance)

| BOM § | Item | ASIN | Qty | $ | Notes |
|---|---|---|---:|---:|---|
| §1 | ESP32-DevKitC-32E | B09MQJWQN2 | 1 | $11.00 | Main controller board |
| §1 | Meshnology ESP32-S3 1.28" rotary display | B0G5Q4LXVJ | 1 | $47.76 | UI display board |
| §1 | ESP32 DIN-rail breakout | B0BW4SJ5X2 | 1 | $25.99 | |
| §1 | MCP23017 I2C GPIO expander | B07P2H1NZG | 1 | $12.99 | |
| §1 | Mean Well IRM-90-12ST PSU | B0CNRST18V | 1 | $31.66 | LRS-200-12 alternate already on hand if BOM swap considered |
| §2 | Control Devices SV-100 PRV | B0D361X97X | 1 | $16.06 | |
| §3 | SEAFLO 22-Series 12 V pump | B0166UBJX4 | 1 | $48.25 | |
| §3 | John Guest 1/4"×1/8" NPT push-fit | B07V6XKZG9 | 1 | $5.00 | |
| §4 | Wellbom CO2 regulator | B0G13P5PMY | 1 | $44.99 | Forward-plan SKU; never ordered (TAPRITE B00L38DRD0 acquired is different) |
| §5 | Frigidaire ice-maker donor | B07PCZKG94 | 1 | $78.70 | **See caveats — alternate donor B0F42MT8JX may cover unit #1** |
| §5 | Supco SUD8358 drier | B009AX2O5W | 1 | $13.40 | |
| §8 | Kamoer KPHM400 pump | B09MS6C91D | 1 | $32.55 | 3 acquired, 2 in prototype, 1 left → need 1 more |
| §8 | Platypus 1 L SoftBottle bladder | B08PG3GMQ8 | 2 | $46.98 | All bladder variants consumed by prototype |
| §9 | Westbrass R2031-NL-62 8" Touch-Flo faucet | B07KH285GJ | 1 | $31.28 | Forward-plan SKU; never ordered |
| §9 | DIGITEN G3/8" Hall-effect flow sensor | B07QQW4C7R | 1 | $7.99 | Forward-plan SKU; G1/4" variants on hand are different |
| §12 | DEVMO MINI float switch (donor) | B07T18PGJ4 | 1 | $13.93 | |
| | **Single-unit subtotal** | | | **~$468.53** | |

### Pack purchases (cover prototype shortfall + future units)

| BOM § | Item | ASIN | $ | Notes |
|---|---|---|---:|---|
| §6 | Fiberglass Supply Depot 2 lb pour-in-place PU foam kit | B08R7TX8QJ | $39.99 | Long-standing LIKELY-TO-BUY; never ordered |
| §8 | Beduan 12 V solenoid valve (~10 more) | B07NWCQJK9 | ~$96.40 | BOM needs 12; ~3 on hand. Long-known shortage |
| §8 | PureSec TWS1414 Y splitter (10-pk) | B01N5I1ZJC | $7.99 | Forward-plan SKU; never ordered |
| §11 | Zip ties (200-pk) | B0BC1VH4XB | ~$6.00 | Forward-plan SKU; never ordered |
| | **Pack subtotal** | | **~$150.38** | |

**Grand total to fully provision unit #1: ~$618.91 + tax/ship.**

## Items confirmed sufficient for unit #1

Already covered, no order needed:

- **§1 Controllers/electronics:** Waveshare RP2040 LCD (qty 2), L298N 4-pack, ULN2803 10-pack, Teyleten relays (5-pack + 1 = 6 on hand)
- **§2 Vessel:** LTWFITTING 5-pack, FERRODAY sparge stone 2-set (1 left), Millrose PTFE tape, Tap Magic fluid, Cambro 6 QT (qty 2 across the ledger), 316L tube and endcap stock on order from OnlineMetals + SendCutSend
- **§3 Water inlet:** Hooshing 2-pack (1 left), Sealproof PVC, LOKMAN clamps 20-pack, MAACFLOW 4-pack, GASHER check valves (3 packs = 6 valves with the Apr 27 spares delivery), Lifevant tubing, John Guest bulkhead (qty 2, 1 left), Multiplex backflow preventers (5 on order across two vendors)
- **§4 CO2:** 5/16" CO2 line + clamps, DERPIPE 5-pack (4 left, but see caveats)
- **§5 Refrigeration:** GOORY 50 ft copper coil (1/2 roll left), DS18B20 5-pack (3 left), MXR C14 inlet 10-pack, Monoprice cord 6-pack, Enviro-Safe R-600a 3-pack (~12 charges), 3M 425 foil tape (12 builds per roll, on order)
- **§8 Flavor:** Pogo pin 2-pair (1 pair left), Platypus Hoser kit (qty 2, 1 left), 1/8" silicone tubing (qty 2, 1 roll left), Supply Depot BIB 2-pack (1 left)
- **§9 Dispensing:** VALVENTO compression 2-pack (1 left), VALVENTO 1/4" tube 5-pack (4 left)
- **§10 UI:** KRAUS air switch (qty 3, 2 left)
- **§11 Wiring:** Dupont jumpers 120-pack, female spade 60-pack, male spade 100-pack
- **§12 Level sensing:** Tandefio 1/8" 316 SS rod 5-pack (10 vessels per pack, on order), Gebildet reed switch 6-pack (4 left after prototype)

## Caveats / open questions

1. **Frigidaire donor — possible $78.70 savings.** purchases.md §6 has both **B07PCZKG94 Frigidaire** ($78.70) and **B0F42MT8JX generic** ($63.80), qty 1 each. The BOM specifies Frigidaire by ASIN, but the parts harvested (compressor / condenser / cap-tube / drier) are generic — the alternate donor should function equivalently. If the prototype consumed only one, the other is available for unit #1. Worth a visual confirmation of which donor is in the prototype before placing a third order.

2. **PETG filament inventory not measured.** BOM §7 estimates **8 kg per unit**. Bambu Lab orders include several PETG spools (Black ×4 in line 293, Translucent Clear ×4 in line 298, plus the founding-purchase color assortment) but exact remaining stock isn't tracked. If prototype consumed multiple kg, unit #1 may run short. Worth a physical spool count before assuming PETG is covered.

3. **DERPIPE 5/16" push-to-connect (B09LXVGPG7)** — flagged in BOM as delisted on Amazon. 4 left in the existing 5-pack covers unit #1, but plan a replacement SKU search before unit #2.

4. **Mean Well IRM-90-12ST vs LRS-200-12.** Both acquired (qty 1 each). If prototype is using the IRM-90 specified by the BOM, unit #1 needs another IRM-90 — or formally swap to the LRS-200 (already on hand but larger physical envelope per BOM §1 rationale). The IRM-90 at 190 cm³ vs LRS-200's 288 cm³ matters for under-counter packaging, so the BOM choice is intentional.

5. **Forward-plan SKU swaps need a "still the right pick?" review** before ordering:
   - **Wellbom B0G13P5PMY** regulator — vs TAPRITE E-T742 B00L38DRD0 already acquired ($96.47). If TAPRITE works, swap the BOM and save the $44.99 buy.
   - **Westbrass R2031-NL-62 B07KH285GJ** faucet — vs three other Westbrass SKUs already on hand (B0BXFW1J38, B01MZ6JPXW, B01N5LVNQA). Worth confirming the visual/feature delta justifies the swap.
   - **DIGITEN G3/8" B07QQW4C7R** flow sensor — vs G1/4" B07QRXLRTH and B07QS17S6Q already on hand. The thread size mismatch is real, but it's worth confirming whether a 3/8"→1/4" adapter would let the on-hand sensors work.

## What this snapshot is NOT

- Not a shopping list to act on right now (~1 month before unit-#1 order placement).
- Not a static record of the BOM — that's `bom.md`.
- Not a procurement decision document — that requires the SKU-swap review noted above and possible BOM updates first.
- Not maintained going forward. **When re-running this audit, generate a fresh dated snapshot rather than editing this one.**

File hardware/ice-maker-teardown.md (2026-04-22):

# Ice Maker Teardowns

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

## Two architectural paths for the cold core

As of 2026-04-18, the cold core design has two live options. Keep-vs-discard decisions below depend on which path wins.

- **Path A — custom SS carbonator + new evaporator coil.** Discard the factory finger-plate evaporator; wind a custom copper coil around a fabricated 304 SS racetrack carbonator. Refrigerant loop must be opened (cut into the suction and cap-tube sides of the factory evaporator), so factory charge must be vented, drier replaced, system evacuated, and recharged. This path is the one `future.md` describes.
- **Path B — factory evaporator kept in place, FDM-printed pressure vessel around it.** Keep the factory finger-plate evaporator wired in-circuit, exactly as shipped. Surround it with a PA6-CF structural shell lined with TPU (the TPU is the pressure boundary; the CF shell carries hoop stress). The refrigerant loop is never opened — factory charge stays sealed, no vent / recharge needed. The evaporator's cold fingers become the internal geometry of the vessel.

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

---

## Unit A — Generic countertop, 8 cubes / 6 min

- ASIN: **B0F42MT8JX**
- Price: $63.80
- Rated output: 26 lb/day
- First teardown: 2026-04-17

### Refrigerant

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

### Refrigerant circuit topology (verified by disassembly)

```
    ┌── discharge ──► condenser ──► filter-drier ──► capillary tube ──┐
    │                                                     (bonded to   │
compressor                                                suction line)│
    │                                                                  ▼
    └── suction ◄──────────────────────────────── evaporator ◄─────────┘

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

    not in the loop: compressor process tube (factory charge port, dead-end stub)
```

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

### Compressor

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

### Condenser

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

### Filter-drier

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

Label on this unit's drier:

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

### Capillary tube + suction-line heat exchanger

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

Physical path through this unit, start to finish:

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

### Process tube (the "dead-end" copper stub)

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

### Hot-gas bypass solenoid (DISCARD for our use)

A small AC solenoid valve is teed into the refrigerant circuit:

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

### Evaporator cold plate

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

### Powering and control (AC wiring)

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

For ESP32 control:
- **Reserved GPIO: pin 14** on the main ESP32-DevKitC-32E. Not a strap pin, not input-only, not reserved for flash/PSRAM. See `hardware/wiring/future-esp32-pinout.mmd` for the full pin map.
- **Preferred: solid-state relay (SSR)** on the AC hot leg. 25 A SSRs (Fotek SSR-25 DA class or a quality-tier Crydom) take 3–32 VDC on the input and switch 120/240 VAC on the output. ESP32 GPIO drives the input directly. Mount to a heatsink — expect ~1 W dissipation per amp switched. Zero-crossing SSRs reduce EMI from inductive switching.
- Alternative: a mechanical motor-rated relay or contactor (e.g. Omron LY2) driven by a small NPN transistor + flyback diode from the ESP32. Works fine, audibly clicks, limited cycle life.
- **Firmware must enforce the 3-minute minimum-off-time** as a guard — the SSR will switch every loop iteration if told to, and that will destroy the compressor within days. Wrap the ON/OFF call behind a "can I switch right now?" check against the last-transition timestamp. A hysteresis band around the temperature setpoint (e.g., ±1 °C) is needed for the same reason — you want long cycles, not rapid thrash.

### Summary — keep vs discard for this unit

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

### Open items

- Factory refrigerant charge mass (read from the nameplate once fully exposed)
- Compressor rated cooling capacity in W — confirm against expected load of holding ~1.5 L of carbonated water at 2 °C against cabinet-ambient
- Physical dimensions of compressor + condenser pair, for enclosure layout
- Decide whether to save photos to `hardware/ice-maker-teardowns/unit-a-b0f42mt8jx/raw-images/` alongside this doc

---

## Unit B — Frigidaire EFIC117-SS

- ASIN: **B07PCZKG94**
- Price: $78.70
- Rated output: 26 lb/day
- Teardown: pending

To be filled in after teardown.

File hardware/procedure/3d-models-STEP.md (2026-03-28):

# STEP Generation Standards

This document defines the standards for programmatic STEP file generation in this project. Every custom part gets a Python script that generates its STEP file. The script IS the parametric model — it must faithfully represent the physical geometry of the part and every interface it engages with.

---

## 1. What These Models Are

These are **engineering models** — precise 3D solids that a 3D printer, CNC machine, or CAD operator could use to produce the part. They are not approximations, not simplified placeholders, not "close enough."

That means:
- Every dimension is caliper-verified or derived from caliper-verified measurements
- Every interface with an off-the-shelf component matches that component's actual physical geometry — its real shape, real profile, real mounting features
- Features exist because they serve a mechanical function, and the model must reflect that function faithfully
- The script demonstrates that the author understood the physical reality of every feature and interface

Off-the-shelf parts that interface with custom parts have **caliper-verified geometry descriptions and reference photographs** in `../off-the-shelf-parts/`. Each part's `extracted-results/geometry-description.md` contains dimensioned descriptions, ASCII art profiles, and references to numbered caliper photos in the sibling `raw-images/` directory. These are the authoritative source for purchased component geometry — the geometry descriptions explain the measurements, and the photographs show the actual physical object being measured.

---

## 2. Script Format

- **Language:** Python 3
- **Library:** CadQuery (standardized — not build123d)
- **Python:** `tools/cad-venv/bin/python3` (virtual environment with CadQuery installed)
- **Validation helper:** `import step_validate` from `tools/step_validate.py` (add `tools/` to `sys.path`)
- **Output:** STEP file (`.step`)
- **Script location:** `hardware/printed-parts/<part-name>/generate_step_cadquery.py`
- **Output location:** `hardware/printed-parts/<part-name>/<part-name>-cadquery.step`
- **Self-contained:** The script must run standalone with no external dependencies beyond CadQuery and `step_validate`
- **Commented:** Each modeling section references the feature name from parts.md

### Why CadQuery

CadQuery was chosen over build123d after comparative evaluation on the cartridge release plate:

1. **Workplane model reduces orientation errors.** CadQuery's "declare plane → sketch 2D → extrude" maps directly to how specs describe features. build123d's `Rot() * Pos() * Primitive()` requires mental simulation of rotation matrices — a reliable source of agent errors.
2. **Explicit orientation parameters.** `slot2D(length, width, angle=90)` self-documents intent. build123d's `SlotOverall` has no angle parameter — the slot's long axis is implicitly determined by sketch axis mapping, which caused a confirmed 90-degree rotation bug.
3. **Revolved profiles for stepped bores.** A bore's full axial cross-section (multiple diameters + chamfers) can be defined as a list of (R, Y) points and revolved once. This is correct-by-construction — no edge hunting for chamfer targets.
4. **Point-in-solid validation via OCP.** CadQuery exposes OCCT's `BRepClass3d_SolidClassifier` through its OCP bindings, enabling spatial probes that verify actual geometry, not just face/edge topology.
5. **`centered=False` eliminates positioning math.** Boxes placed at spec coordinates directly, without computing center offsets.

---

## 3. Source Material

For each part being modeled, the complete specification chain is:

1. **The part's `planning/parts.md`** — dimensions, features, interfaces, assembly notes
2. **Cross-referenced geometry descriptions** — linked from parts.md for every off-the-shelf component that mounts in or interfaces with the custom part (in `off-the-shelf-parts/*/extracted-results/geometry-description.md`)
3. **Reference photographs** — caliper photos of the physical off-the-shelf parts (in `off-the-shelf-parts/*/raw-images/`), referenced by number in the geometry descriptions
4. **Research files** — linked from parts.md, containing design analysis and rationale
5. **Requirements and vision** — `hardware/requirements.md` and `hardware/vision.md`

Every cross-reference in parts.md is a relative path. Follow them all. Read the geometry descriptions. Look at the photographs. Understand what you are modeling before you write a line of code.

---

## 4. Self-Review Rubrics

Apply these rubrics **during and after** generation. Rubrics 1 and 2 are completed before writing modeling code. Rubrics 3-5 are applied after the model is generated.

### Rubric 1 — Feature Planning Table (MANDATORY, before coding)

Before writing any modeling code, read parts.md and enumerate **every** feature in a table. Every line item under "Features" and "Interfaces" in parts.md becomes a row. If parts.md says there are N features, the table has N rows. Missing a row means missing a feature in the model.

For each feature:

```
| # | Feature Name | Mechanical Function | Operation | Shape | Axis | Center Position (X,Y,Z) | Dimensions | Notes |
```

Column definitions:
- **Feature Name**: Exact name from parts.md (e.g., "guide pin slot", "tube clearance hole")
- **Mechanical Function**: WHY this feature exists — what it does in the assembly. A slot that allows sliding is fundamentally different from a decorative groove, even if the dimensions are identical. Getting the function right determines whether you get the orientation, tolerances, and shape right.
- **Operation**: Add (boss, pad, extrusion) or Remove (bore, pocket, slot, cut-through)
- **Shape**: Cylinder, box, stadium/slot, chamfer, etc.
- **Axis**: Which axis the feature runs along (X, Y, or Z). For through-features, this is the axis you'd drill along.
- **Center Position**: Where the feature center is in the part's coordinate system
- **Dimensions**: All relevant dimensions from parts.md
- **Notes**: Clearance requirements, tolerances, interface constraints

This table is the contract between the specification and the model. Print it to stdout when the script runs.

### Rubric 2 — Coordinate System Declaration (MANDATORY, before coding)

Declare the part's coordinate system explicitly at the top of the script:

```
# Coordinate system:
#   Origin: [where — e.g., "plate bottom-left-front corner"]
#   X: [what — e.g., "plate width, left to right"]
#   Y: [what — e.g., "plate depth, front to back"]
#   Z: [what — e.g., "plate height, bottom to top"]
#   Envelope: [W]x[D]x[H] mm → X:[0,W] Y:[0,D] Z:[0,H]
```

Map parts.md dimensions to axes explicitly. When parts.md says "59W x 47H x 6D", that must map to specific axes with specific ranges. This prevents the class of error where width and depth get swapped or a feature ends up on the wrong face.

### Rubric 3 — Feature-Specification Reconciliation (MANDATORY, after generation)

After generating the model, the script must programmatically verify **every row** of the Feature Planning Table against the actual solid using point-in-solid probing. Use the `Validator` class from `tools/step_validate.py`.

For each feature, probe specific spatial coordinates to verify:

1. **Existence**: `check_void()` inside bores/slots/holes, `check_solid()` inside bosses/tabs/walls. If a feature is missing, the probe will detect solid where void is expected (or vice versa).
2. **Dimensions**: Probe at the expected boundary radius/edge. A point just inside the bore radius should be void; a point just outside should be solid. Wrong diameter → wrong probe result.
3. **Position**: Probe at the feature's expected center coordinates. Wrong position → probe hits wrong material state.
4. **Orientation**: For directional features (stadium slots, elongated cutouts), probe at both ends of the long axis AND at the midpoint of the short axis. A 90-degree rotation error will cause the long-axis probe to hit solid instead of void.

Example validation pattern for a stadium slot with long axis along Z:

```python
# Slot center — should be void
v.check_void("Slot center", sx, mid_y, sz, "void at slot center")

# Long-axis ends (Z direction) — should be void if orientation is correct
v.check_void("Slot Z+ end", sx, mid_y, sz + SLOT_L/2 - 0.3, "void near top of slot")
v.check_void("Slot Z- end", sx, mid_y, sz - SLOT_L/2 + 0.3, "void near bottom of slot")

# Short-axis extents (X direction) — should be SOLID if orientation is correct
# (probing outside the 3.3mm width but inside the 7.3mm length)
v.check_solid("Slot X+ wall", sx + SLOT_W/2 + 0.5, mid_y, sz, "solid outside slot width")
```

If the slot were rotated 90 degrees, the Z+ end probe would hit solid (the slot only extends 3.3mm in Z instead of 7.3mm), catching the bug.

**Zero FAILs required.** If any feature fails, fix it before exporting the STEP.

### Rubric 4 — Solid Validity

After the final boolean operation, verify using `Validator`:

```python
v.check_valid()         # No self-intersecting faces
v.check_single_body()   # One connected solid, not fragmented
v.check_volume(expected_envelope=W*D*H, fill_range=(0.5, 1.2))
```

### Rubric 5 — Bounding Box Reconciliation

Query the model's actual bounding box and compare against the envelope from parts.md using `Validator.check_bbox()`. Check all three axes, accounting for features that intentionally extend beyond the base body (tabs, bosses).

If the bounding box is SMALLER than expected in any dimension → likely missing a protruding feature.
If the bounding box is LARGER than expected in an unexpected dimension → likely a feature in wrong orientation.

---

## 5. CadQuery Techniques

Preferred patterns for common modeling tasks:

### Stepped bores with chamfers — use revolved profiles

Define the full axial cross-section as a list of (R, Y) coordinate pairs and revolve once. This includes all diameter steps and chamfers in a single operation — no edge filtering, no silent failures.

```python
# Example: 3-stage stepped bore with entry chamfer
profile_pts = [
    (0,              0),           # axis at entry face
    (R_OUTER - C,    0),           # chamfer start
    (R_OUTER,        C),           # chamfer end
    (R_OUTER,        DEPTH_1),     # step to next diameter
    (R_INNER,        DEPTH_1),     # inner bore wall
    (R_INNER,        DEPTH_2),     # step to smallest
    (R_TUBE,         DEPTH_2),     # tube hole wall
    (R_TUBE,         FULL_DEPTH),  # through to back face
    (0,              FULL_DEPTH),  # axis at back face
]

bore = cq.Workplane("XY").polyline(profile_pts).close().revolve(360, (0,0), (0,1))
plate = plate.cut(bore.translate((cx, 0, cz)))
```

### Positioning — use `centered=False` and `translate()`

Place boxes at spec coordinates directly:

```python
plate = cq.Workplane("XY").box(W, D, H, centered=False)  # X:[0,W] Y:[0,D] Z:[0,H]
```

### Stadium slots — use `slot2D()` with explicit `angle`

Always specify the `angle` parameter. The long axis of the slot is along the sketch X by default; `angle=90` rotates it to sketch Y (which maps to Z on the XZ workplane).

```python
slot = (
    cq.Workplane("XZ")
    .center(slot_cx, slot_cz)
    .slot2D(SLOT_LENGTH, SLOT_WIDTH, angle=90)  # long axis along Z
    .extrude(-PLATE_D)  # XZ normal is -Y; negative extrude goes +Y
)
```

### Extrude direction on non-XY workplanes

CadQuery's `extrude(positive)` goes along the workplane normal, `extrude(negative)` goes opposite. Workplane normals:
- `"XY"` → +Z
- `"XZ"` → -Y
- `"YZ"` → +X

Comment the extrude direction when using XZ or YZ workplanes.

---

## 6. Validation Helper

The validation helper at `tools/step_validate.py` provides the `Validator` class. Import it at the top of each generation script:

```python
import sys
from pathlib import Path
sys.path.insert(0, str(Path(__file__).resolve().parents[3] / "tools"))
from step_validate import Validator
```

After building the model:

```python
v = Validator(plate)  # plate is the CadQuery Workplane

# Feature probes (one section per Feature Planning Table row)
v.check_solid("Plate body interior", 29.5, 3.0, 23.5)
v.check_void("Bore 1 center", 9.5, 1.0, 9.5)
# ... etc for every feature ...

# Bounding box
bb = plate.val().BoundingBox()
v.check_bbox("X", bb.xmin, bb.xmax, expected_xmin, expected_xmax)
v.check_bbox("Y", bb.ymin, bb.ymax, expected_ymin, expected_ymax)
v.check_bbox("Z", bb.zmin, bb.zmax, expected_zmin, expected_zmax)

# Solid integrity
v.check_valid()
v.check_single_body()
v.check_volume(expected_envelope=W*D*H)

# Summary — exits 1 on any failure
if not v.summary():
    sys.exit(1)
```

---

## 7. Workflow

1. Read the part's `planning/parts.md` and follow **every** cross-reference (geometry descriptions, research, architecture)
2. Look at reference photographs of interfacing off-the-shelf parts
3. Complete the Feature Planning Table (Rubric 1) and Coordinate System Declaration (Rubric 2)
4. Write the modeling code using CadQuery, referencing the planning table for every feature
5. Write the validation section using `Validator`, with probes for every feature
6. Run the script with `tools/cad-venv/bin/python3`
7. Verify all checks pass (zero FAILs)
8. Fix any failures and re-run until all checks pass
9. Export STEP file

---

## 8. Related Documents

- **Drawing standards (SVG):** `hardware/procedure/engineering-drawings-SVG.md`
- **Validation helper source:** `tools/step_validate.py`
- **Off-the-shelf part geometry and photographs:** `hardware/off-the-shelf-parts/*/`

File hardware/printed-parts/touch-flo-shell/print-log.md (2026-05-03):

# touch-flo-shell print log

Format: facts only. Direct quotes from Derek where applicable. Settings observed in committed `.3mf` snapshots. No interpretation, no hypothesis.

## Pre-PET-CF test print (PETG with PLA supports)

Derek said:
- "Getting support material out of the dispense tube is going to be tough"
- "The zone 4.5 to zone 5 transition is the structural weak point and snaps easier than I would like, even though this was PETG and we will be printing in PET-CF"

## PET-CF print attempt 1

Derek said:
- "While printing, I have now twice in the first 2 hours gotten alerts 'please check the filament is still pushed in', and it was, and each time it then asked 'is it now extruding?' and it was."
- "The first time I got the alert, it immediately went back to that alert several times in a row after starting to print just a few mm, but then eventually it started going again and was fine for like 30 minutes until I got the next alert."
- "I went ahead and pushed the PTFE tube way further into the Sunlu E2"
- "Ended up printing nothing after I tapped 'it was visible now' when it apparently was not — got tired of monitoring it. Found it clogged above the hot end, had to take things apart there to get it all out."

## PET-CF print attempt 2

Derek said:
- "Got it reloaded now, starting attempt #2 .... redid all the PTFE and feeding of it entirely, checked all connections, used a shorter PTFE run."
- "Well attempt #2 failed as well same thing, got a clog, I had to take more things apart to clean it this time"

## PET-CF print attempt 3 (calibration phase)

Derek said:
- "tried #3 I am now getting 'nozzle offset calibration' failed over and over"
- Error code reported: `0300-4010 180102`
- "Alright .... finally got a couple good calibrations."

## PET-CF print attempt 4 (after calibration restored)

Derek said:
- "At about layer 20 I peaked at the print and saw that somewhere around layer 15 we started printing air. At first I saw some threading sticking up"
- "I hit unload and it unloaded just fine. I hit load and it loaded just fine. No clog."

## PET-CF print attempt 5 (clean slate, settings per commit `df00c36`)

Derek said:
- "We made it to layer 33 and no air print yet — furthest it has gotten so far I think."
- "I need to switch the 'add support' angle to add more supports — I think I might have had it at the default 35, but I'd been bumping it to 45 at least on most prints and had forgotten here perhaps"
- "I see some very stupid things happening that seem like they are going to crash the print, but they haven't exploded yet"

Observed in `df00c36` 3mf:
- `support_threshold_angle`: 25 (Derek's recollection of the default was 35; observed value is 25)
- `support_angle`: 0
- `support_critical_regions_only`: 0

TODO for next slice: bump `support_threshold_angle` per Derek's "at least 45" practice for prints with significant overhangs. Reminder to self if the print crashes mid-air later: insufficient supports were a known concern at layer 33 of attempt 5.

Derek observed during the print:
- "I see a few places where it is an entirely solid array, think like dozens of walls, and within that, there are a few stray strands curling up, like it printed air for a micro second, or perhaps it printed too thinly of a line momentarily, or perhaps it printed fine and just something else is wrong that is causing a single 1 mm strand to break off and curl upward in the middle of an otherwise solid print."
- "In some cases I have sent it print over these things just fine and the next layer at least has the 'short curly threads' in different spots"

Action: at layer 40 of this print, Derek turned the E2 back on to 60°C (it had been off; last run 23+ hours before the print started).

Environmental readings during attempt 5 (Sunday May 3rd 2:48 AM, layer 44):
- Basement EcoBee: 64 °F
- Upstairs EcoBee: 70 °F, 38% humidity
- Garage Shelly: 61 °F, 34% humidity
- Deck Shelly: 55 °F, 41% humidity
- Upstairs Bathroom Shelly: 18 °C, 40% humidity
- Master Bathroom Shelly: 64 °F, 39% humidity
- Downstairs Bathroom Shelly: 64 °F, 42% humidity

Two sensors nearest the 3D printer:
- Basement EcoBee: 64 °F
- Downstairs Bathroom Shelly: 64 °F, 42% humidity

## End of attempt 5 (print finished)

Derek observed:
- More air gaps in the finished print
- Some places: "many layers in a row [of air gaps] before starting again"
- Some places: air gaps consistently start "either at the end or at the beginning of a layer only"
- Base plate (printed simultaneously, "walls only" mode):
  - "the center of the base plate, the innermost 90% is solid"
  - "the outermost portion of it (whatever printed last or first) there is a 'wobble' of air gaps where some layers printed more of that, some printed more air, of that outermost 10%"

Derek observed on the prime tower (after tearing it apart):
- "the first 10 layers on the PET-CF look fine"
- "from there on up we what might be described best as 'stringing' (filament not fused to what is next to it or below it or above it, i.e. raw 'strings' of filament)"
- "The ABS side looks solid and well fused throughout"

## Plans for attempt 6

Derek's plan:
- Next print: base plate only, no supports
- Before printing: re-dry the filament for 12 hours at 85°C
- Bambu wiki confirms 85°C for PET-CF
- The filament's box also specifies 85°C
- Derek stated: "I have seen evidence of moisture being a problem since even when it was most recently dried"

## Hardware / setup observations across all PET-CF attempts

Derek said:
- "I have not been running the E2 for any of this ... it has been 23 hours since the E2 was last ran and the last 8 hours of trial and error have nothing to do with 'E2 at 70'"
- "I have been switching through my 3 different 0.4 nozzles throughout this. So they may all be contaminated in ways I cannot see, but they all look fine to me."
- On clumping detection (probing): "it has been on for all prints so far"
- "Well ... I don't see any purging during prints"

PET-CF surface quality, when it printed:
- "I don't see layer lines like I have on everything else — if they're there, they are invisible to my eyes. It really does look great, a whole different ballgame than everything else we've been printing with (ABS, PETG, PLA)"

## 3mf snapshots committed

### Commit `145a852` — saved during in-flight print

Filament slots in project: PET-CF (slot 0), ABS, ABS, ABS, PETG, PETG, PETG, PET-CF, PLA
Active in slice: PET-CF (left) + ABS (right, supports)
Support filament: ABS
Support interface filament: ABS

PET-CF settings:
- `nozzle_temperature`: 280°C
- `filament_flow_ratio`: 0.94
- `filament_retraction_length`: 1.2 mm (override)
- `filament_retract_before_wipe`: 70% (override)
- `filament_max_volumetric_speed`: 5 mm³/s
- `chamber_temperatures`: 50°C

ABS settings:
- `chamber_temperatures`: 65°C
- Effective chamber for slice: 65°C (max wins)

Process settings:
- `layer_height`: 0.24 mm
- `outer_wall_speed`: 200 mm/s
- `inner_wall_speed`: 300 mm/s
- `sparse_infill_speed`: 350 mm/s
- `enable_pressure_advance`: 0
- `enable_prime_tower`: 1
- `enable_wrapping_detection`: 1 (clumping detection by probing enabled)
- `wrapping_detection_layers`: 20 (probes triggered at layer_num 3, 10, 19 per gcode)

### Commit `e0752d9` — resaved during in-flight print
Same settings as `145a852`. File-byte delta only. `enable_wrapping_detection`: 1.

### Commit `df00c36` — clean slate

Filament slots in project: PET-CF (slot 0), ABS (slot 1)
Active in slice: PET-CF (left) + ABS (right, supports)
Support filament: ABS
Support interface filament: ABS

PET-CF settings:
- `nozzle_temperature`: 270°C
- `filament_flow_ratio`: 1.0
- `filament_retraction_length`: nil (no override; uses printer default)
- `filament_retract_before_wipe`: nil (no override)
- `filament_max_volumetric_speed`: 5 mm³/s
- `chamber_temperatures`: 50°C

ABS settings:
- `chamber_temperatures`: 65°C
- Effective chamber for slice: 65°C (max wins)

Process settings:
- `layer_height`: 0.16 mm
- `outer_wall_speed`: 60 mm/s
- `inner_wall_speed`: 150 mm/s
- `sparse_infill_speed`: 180 mm/s
- `enable_pressure_advance`: 0
- `enable_prime_tower`: 1
- `enable_wrapping_detection`: 0 (clumping detection by probing disabled)
- `wrapping_detection_layers`: 20 (gcode unchanged; would trigger at layer_num 3, 10, 19 if enabled)

## Evidence that `enable_wrapping_detection` might be probe detection in the UI

- Wiki language for the feature: "the nozzle is detected to be wrapped by filament" — "wrapping" describes what clumping is physically ([Bambu Wiki: Nozzle Clumping Detection by Probing](https://wiki.bambulab.com/en/software/bambu-studio/nozzle-clumping-detection-by-probing))
- Behavior match in the gcode: `wrapping_detection_gcode` in the 3mf moves the toolhead to the back of the bed and runs `G39` (probe) at `layer_num` 3, 10, 19 — matching the wiki's "probes at layers 4, 11, 20" (same triggers, 0- vs 1-indexed)
- Trigger-layer alignment: 4 / 11 / 20 layers in the wiki match the gcode's 3 / 10 / 19 (zero-indexed)

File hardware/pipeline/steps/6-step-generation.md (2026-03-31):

# STEP Generation Standards

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

---

## 1. What These Models Are

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

---

## 2. Script Format

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

### Why CadQuery

CadQuery was chosen over build123d after comparative evaluation on the cartridge release plate:

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

---

## 3. Source Material

For each part being modeled, the complete specification chain is:

1. **The part's `parts.md`** — dimensions, features, interfaces, assembly notes
2. **Cross-referenced geometry descriptions** — linked from parts.md for every off-the-shelf component that mounts in or interfaces with the custom part (in `off-the-shelf-parts/*/extracted-results/geometry-description.md`)
3. **Reference photographs** — caliper photos of the physical off-the-shelf parts (in `off-the-shelf-parts/*/raw-images/`), referenced by number in the geometry descriptions
4. **Research files** — linked from parts.md, containing design analysis and rationale
5. **Requirements and vision** — `hardware/requirements.md` and `hardware/vision.md`

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

---

## 4. Self-Review Rubrics

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

### Rubric 1 — Feature Planning Table (MANDATORY, before coding)

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

For each feature:

```
| # | Feature Name | Mechanical Function | Operation | Shape | Axis | Center Position (X,Y,Z) | Dimensions | Notes |
```

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

### Rubric 2 — Coordinate System Declaration (MANDATORY, before coding)

Declare the part's coordinate system explicitly at the top of the script:

```
# Coordinate system:
#   Origin: [where — e.g., "plate bottom-left-front corner"]
#   X: [what — e.g., "plate width, left to right"]
#   Y: [what — e.g., "plate depth, front to back"]
#   Z: [what — e.g., "plate height, bottom to top"]
#   Envelope: [W]x[D]x[H] mm → X:[0,W] Y:[0,D] Z:[0,H]
```

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

### Rubric 3 — Feature-Specification Reconciliation (MANDATORY, after generation)

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

For each feature, probe specific spatial coordinates to verify:

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

5. **Path continuity**: For every pair or chain of features that must form a continuous void path (fastener clearance hole + insert bore, stepped counterbore, fluid channel segments, wire routing channels), probe at the transition depth from both sides. A probe at `transition_depth - 0.1mm` AND `transition_depth + 0.1mm` must both return void. If either returns solid, the features do not connect — flag the failure and fix the geometry before exporting. Do not rely on each feature passing its own existence probe independently; two blind holes that don't meet are each individually "present" but together form a blocked path.

Example pattern for a clearance hole (Y=0→5.5) meeting an insert bore (Y=5.5→10) at Y=5.5:

```python
# Probe both sides of the transition at Y=5.5
v.check_void("Hole→bore transition below", cx, 5.4, cz, "void just below transition — clearance hole reaches it")
v.check_void("Hole→bore transition above", cx, 5.6, cz, "void just above transition — insert bore reaches it")
# If either probe fails, a solid plug exists at the transition — path is blocked.
```

Example validation pattern for a stadium slot with long axis along Z:

```python
# Slot center — should be void
v.check_void("Slot center", sx, mid_y, sz, "void at slot center")

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

# Short-axis extents (X direction) — should be SOLID if orientation is correct
# (probing outside the 3.3mm width but inside the 7.3mm length)
v.check_solid("Slot X+ wall", sx + SLOT_W/2 + 0.5, mid_y, sz, "solid outside slot width")
```

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

**Zero FAILs required.** If any feature fails, fix it before exporting the STEP.

### Rubric 4 — Solid Validity

After the final boolean operation, verify using `Validator`:

```python
v.check_valid()         # No self-intersecting faces
v.check_single_body()   # One connected solid, not fragmented
v.check_volume(expected_envelope=W*D*H, fill_range=(0.5, 1.2))
```

### Rubric 5 — Bounding Box Reconciliation

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

---

## 5. CadQuery Techniques

Preferred patterns for common modeling tasks:

### Stepped bores with chamfers — use revolved profiles

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

```python
# Example: 3-stage stepped bore with entry chamfer
profile_pts = [
    (0,              0),           # axis at entry face
    (R_OUTER - C,    0),           # chamfer start
    (R_OUTER,        C),           # chamfer end
    (R_OUTER,        DEPTH_1),     # step to next diameter
    (R_INNER,        DEPTH_1),     # inner bore wall
    (R_INNER,        DEPTH_2),     # step to smallest
    (R_TUBE,         DEPTH_2),     # tube hole wall
    (R_TUBE,         FULL_DEPTH),  # through to back face
    (0,              FULL_DEPTH),  # axis at back face
]

bore = cq.Workplane("XY").polyline(profile_pts).close().revolve(360, (0,0), (0,1))
plate = plate.cut(bore.translate((cx, 0, cz)))
```

### Positioning — use `centered=False` and `translate()`

Place boxes at spec coordinates directly:

```python
plate = cq.Workplane("XY").box(W, D, H, centered=False)  # X:[0,W] Y:[0,D] Z:[0,H]
```

### Stadium slots — use `slot2D()` with explicit `angle`

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

```python
slot = (
    cq.Workplane("XZ")
    .center(slot_cx, slot_cz)
    .slot2D(SLOT_LENGTH, SLOT_WIDTH, angle=90)  # long axis along Z
    .extrude(-PLATE_D)  # XZ normal is -Y; negative extrude goes +Y
)
```

### Extrude direction on non-XY workplanes

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

Comment the extrude direction when using XZ or YZ workplanes.

---

## 6. Validation Helper

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

```python
import sys
from pathlib import Path
sys.path.insert(0, str(Path(__file__).resolve().parents[3] / "tools"))
from step_validate import Validator
```

After building the model:

```python
v = Validator(plate)  # plate is the CadQuery Workplane

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

# Solid integrity
v.check_valid()
v.check_single_body()
v.check_volume(expected_envelope=W*D*H)

# Summary — exits 1 on any failure
if not v.summary():
    sys.exit(1)
```

---

## 7. Workflow

1. Read the part's `parts.md` and follow **every** cross-reference (geometry descriptions, research, architecture)
2. Look at reference photographs of interfacing off-the-shelf parts
3. Complete the Feature Planning Table (Rubric 1) and Coordinate System Declaration (Rubric 2)
4. Write the modeling code using CadQuery, referencing the planning table for every feature
5. Write the validation section using `Validator`, with probes for every feature
6. Run the script with `tools/cad-venv/bin/python3`
7. Verify all checks pass (zero FAILs)
8. Fix any failures and re-run until all checks pass
9. Export STEP file

---

## 8. Related Documents

- **Drawing standards (SVG):** `hardware/pipeline/steps/5-engineering-drawings.md`
- **Validation helper source:** `tools/step_validate.py`
- **Off-the-shelf part geometry and photographs:** `hardware/off-the-shelf-parts/*/`

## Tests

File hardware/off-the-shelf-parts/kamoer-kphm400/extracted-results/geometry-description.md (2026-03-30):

# Kamoer KPHM400-SW3B25 Peristaltic Pump — Caliper-Verified Geometry Description

## Purpose of This Document

This document describes the physical geometry of the Kamoer KPHM400-SW3B25 peristaltic pump in enough detail that an agent generating engineering drawings or designing a 3D-printed pump tray/cartridge can model every mounting surface, clearance zone, and interface — without holding the part.

**Reference photographs:** Caliper photos of the physical pump are in `../raw-images/`. Photo numbers referenced throughout this document (e.g., "photo 01") correspond to numbered files in that directory.

## Overall Form

The pump is a **two-body assembly**: a black plastic **pump head** housing (roughly square cross-section when viewed from front) permanently attached to a silver cylindrical **DC motor** via a white plastic **adapter plate**. The motor shaft enters the pump head from the rear, driving an internal 3-roller peristaltic mechanism.

When viewed from the front (tube connector face), the pump head appears nearly square with rounded corners. The motor protrudes behind it, creating an elongated overall profile. A **black mounting bracket** (stamped metal plate) sits at the junction between the pump head and motor. The bracket face (the flat surface where the pump head and motor meet) contains **4 mounting holes in a square pattern**, with screws oriented parallel to the motor cylinder axis.

## Axis and Orientation Convention

- **X (width):** Horizontal when pump is in its normal operating orientation.
- **Y (depth):** From front face (tube connectors) toward rear (motor terminals). This is the longest dimension.
- **Z (height):** Vertical. The pump head is roughly symmetric about the XY midplane.
- **Front face:** The face with the Kamoer branding label, yellow priming cap, 4 corner screws, and tube connector exits.
- **Rear:** Motor terminal end.

## Major Sections Along the Y (Depth) Axis

### Section 1: Pump Head Front Face (Y = 0)
- Nearly square when viewed head-on: **~62.6mm wide x ~62.6mm tall** (caliper-verified from multiple photos)
- 4x Phillips head screws at corners (hold the front cover plate on)
- Yellow priming cap at center (small, ~10mm diameter, press-fit)
- "Kamoer KPHM" branding label (black with yellow accent)
- **Two tube connector exits** protrude from this face:
  - White plastic barbed connectors for BPT tubing (4.8mm ID / 8.0mm OD)
  - Positioned offset from center — one above center, one below (or left/right depending on orientation)
  - **Barb protrusion from bracket surface: 34.54mm** (caliper-verified, photo 15) — this is a sub-measurement of the 48.88mm full pump head depth (photo 14), meaning the barbs extend 34.54mm forward of the mounting bracket face

### Section 2: Pump Head Body (Y = 0 to ~48mm)
- Black plastic housing containing the peristaltic roller mechanism
- Cross-section is roughly square with rounded corners, ~62.6mm x ~62.6mm
- Depth of the pump head body: **~47.88–48.88mm** (caliper readings from photos 05/14 area, though see mounting hole notes below)

### Section 3: Mounting Bracket (Y ≈ 48mm)
- Black stamped metal bracket plate at the junction face between pump head and motor
- The bracket face is perpendicular to the motor cylinder axis (i.e., parallel to the pump head's rear face)
- Bracket width: **~68.6mm** (matches datasheet — wider than 62.6mm pump head by ~3mm per side)
- **Mounting holes:**
  - **4x M3 through-holes** in a square pattern on the bracket face (hole diameter: **3.13mm**, caliper-verified from photo 06)
  - **Center-to-center spacing: 50mm x 50mm square** (per datasheet, ±0.1mm)
  - Caliper reference: photo 05 measured 47.88mm edge-to-edge across one pair of holes; photo 06 measured hole diameter at 3.13mm. Edge-to-edge 47.88 + hole diameter 3.13 ≈ 51mm outer edge, consistent with 50mm c-c.
  - The 4 holes surround the motor cylinder — screws pass through the bracket face parallel to the motor axis, threading into the pump head
  - **This is the face where the pump mounts to a surface.** The natural mounting approach is a flat plate with a bore hole for the motor cylinder to pass through, with 4 screw holes surrounding the bore matching this 50mm square pattern.
- Bracket thickness: ~1.5–2mm (estimated from photos)

### Section 4: Motor Adapter Plate (Y ≈ 48–52mm)
- White plastic disc/plate between bracket and motor
- Transitions from the square pump head bolt pattern to the round motor housing

### Section 5: DC Motor Body (Y ≈ 52mm to end)
- Silver cylindrical motor housing (standard 3xx-series DC motor form factor)
- **Motor diameter: 35.73mm** (caliper-verified, photo 16)
- Motor has a flat on one side (standard anti-rotation feature)
- QR code, RoHS label, and Kamoer product label on motor body
- **Motor shaft nub:** A small protrusion from the center of the motor end cap (the non-drive end). This nub accounts for the 5mm difference between the two total-length measurements.
- **Motor terminal end:** Two solder tabs at the very rear

## Total Length Measurements

| Measurement | Value | What It Includes |
|---|---|---|
| Total length (with motor nub) | **116.48mm** | Front face to end of motor shaft nub (photos 07, 08) |
| Total length (without motor nub) | **111.43mm** | Front face to motor end cap, excluding nub (photo 09) |
| Motor shaft nub protrusion | **~5.05mm** | Difference: 116.48 - 111.43 |

## Additional Verified Dimensions

| Photo | Reading | What's Being Measured | Confidence |
|---|---|---|---|
| 01 | 62.61mm | Pump head width, top-down | HIGH |
| 02 | 62.51mm | Pump head width, side view | HIGH |
| 03 | 62.61mm | Pump head width, front view | HIGH |
| 04 | 62.61mm | Pump head width, front face with branding | HIGH |
| 05 | 47.88mm | Mounting hole edge-to-edge spacing (one axis of 4-hole square pattern) | HIGH |
| 06 | 3.13mm | Mounting hole diameter | HIGH |
| 07 | 116.48mm | Total length with motor nub (sideways display) | HIGH (user-verified) |
| 08 | 115.48mm | Total length with motor nub, alt angle | MEDIUM (similar to 07) |
| 09 | 111.43mm | Total length without motor nub (sideways display) | HIGH (user-verified) |
| 10 | ~68.74mm | Pump head depth including front cover | MEDIUM |
| 11 | 65.15mm | Pump body height or depth | HIGH |
| 12 | ~61.19mm | Pump head height, alt angle | MEDIUM |
| 13 | ~51.68mm | Pump head dimension (possibly including bracket) | MEDIUM |
| 14 | 48.88mm | Pump head depth, side view | HIGH |
| 15 | 34.54mm | Distance from mounting bracket surface to furthest edge of inlet/outlet barbs (sub-measurement of photo 14) | HIGH (user-verified) |
| 16 | 35.73mm | Motor body diameter (sideways display) | HIGH (user-verified) |
| 17 | 82.82mm | Height with tube connectors or partial assembly span | MEDIUM |

## Cross-Referencing with Datasheet

The Kamoer datasheet lists: **68.6W x 115.6D x 62.7H mm**

| Dimension | Datasheet | Caliper | Notes |
|---|---|---|---|
| Width (X) | 68.6mm | 62.61mm (head), ~68.6 (with bracket) | Pump head is 62.6mm; bracket extends ~3mm per side beyond pump head |
| Depth (Y) | 115.6mm | 116.48mm (with nub), 111.43mm (without) | Datasheet likely measures to motor end cap |
| Height (Z) | 62.7mm | 62.51–62.61mm | Pump head is nearly square |

## Mounting Hole Pattern — Critical for Pump Tray Design

The mounting holes are on the **junction face** between the pump head and motor — the flat face where the black cube meets the metal cylinder. Screws pass through this face parallel to the motor cylinder axis.

```
VIEW OF THE JUNCTION FACE (looking at the pump from the motor side):

              ◄── 50mm c-c ──►

         ○─────────────────────○
         │                     │  ▲
         │    ╱ ‾ ‾ ‾ ‾ ╲     │  │
         │   │  35.73mm     │    │  50mm c-c
         │   │  motor     │    │  │
         │    ╲ _ _ _ _ ╱      │  ▼
         │                     │
         ○─────────────────────○

    ◄──────── ~68.6mm bracket ────────►
    ◄───── 62.6mm pump head ─────►
```

- **Hole count:** 4 (square pattern)
- **Hole diameter:** 3.13mm (accepts M3 screws with ~0.13mm clearance)
- **Pattern:** 50mm x 50mm square, center-to-center (user-verified)
- **Hole positions:** On the bracket face surrounding the motor cylinder, symmetric about the pump center axis
- **Orientation:** Screws are parallel to the motor/cylinder axis — they thread into the pump head from the motor side
- **Mounting approach:** A flat mounting surface with a bore hole (~37mm+) for the 35.73mm motor cylinder to pass through, with 4 screw holes at 50mm square surrounding the bore

## Clearance Zones for 3D Modeling

When designing a pump tray or cartridge that holds this pump:

1. **Pump head envelope:** 62.6mm x 62.6mm square (rounded corners), ~48mm deep
2. **Bracket/mounting face:** The junction face between pump head and motor has 4x M3 mounting holes in a 50mm square. The bracket is ~68.6mm wide. A mounting surface needs a bore hole for the 35.73mm motor cylinder, surrounded by 4 screw holes at the 50mm square pattern.
3. **Motor protrusion behind bracket:** ~63–68mm cylindrical body (35.73mm diameter) with a 5mm nub at the very end. Total behind bracket: ~68mm.
4. **Tube exit clearance in front:** ~30–50mm of BPT tube stubs protrude forward.
5. **Wiring clearance at rear:** Motor terminals at the back need ~5mm for solder connections.
6. **Total depth budget:** 116mm from front face to motor nub tip, plus tube stubs in front.
7. **Motor nub:** 5mm protrusion at center of motor end — must not bottom out against any tray surface.

## Remaining Unknowns

1. **Tube connector exit positions:** Exact X/Z positions of the two tube stubs on the front face.
2. **Bracket-to-pump-head attachment:** Whether the bracket can be separated from the pump head (for measurement) or is permanently fixed.

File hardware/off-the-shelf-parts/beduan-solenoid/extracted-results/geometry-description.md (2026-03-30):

# Beduan Solenoid Valve (2-Way NC, 1/4" QC) — Caliper-Verified Geometry Description

## Purpose of This Document

This document describes the physical geometry of the Beduan 12V DC normally-closed solenoid valve (Amazon B07NWCQJK9) in enough detail that an agent generating engineering drawings or designing a valve rack can model every surface, mounting zone, and interface — without holding the part.

**Reference photographs:** Caliper photos of the physical valve are in `../raw-images/`. Photo numbers referenced throughout this document (e.g., "photo 03") correspond to numbered files in that directory.

## Overall Form

The valve is a **T-shaped assembly** composed of two distinct sub-bodies:

1. **Valve body (white plastic, fluid section):** Contains the diaphragm/poppet mechanism. Has two tube ports (inlet and outlet) with built-in push-to-connect (quick-connect) fittings for 1/4" OD tubing. The white body is **square in cross-section (32.71mm x 32.71mm)** when the collets and push-connect port stubs are excluded. This is the horizontal bar of the T.
2. **Solenoid coil (metal/black-cased, electrical section):** Electromagnetic coil mounted perpendicular to the valve body, rising vertically from the **center** of the white body. This is the vertical stroke of the T. Has two blade-style spade connector terminals protruding from the top. A Chinese product label on the valve body reads "DC12V 0.02-0.8MPa".

The valve has a **2x2 grid of mounting holes** on one face of the white body. The mounting hole grid outer edge-to-edge dimension is **31.41mm** (photo 04).

## Axis and Orientation Convention

Oriented for typical rack mounting (solenoid coil on top, tube ports horizontal):

- **X (width):** Across the valve body, perpendicular to tube flow direction
- **Y (depth):** Along the tube flow direction (port-to-port axis)
- **Z (height):** Vertical — from mounting surface of white body up through solenoid coil to spade connector tips

## Dimensional Profile

```
FRONT VIEW (X-Z plane, looking along tube flow axis Y):

              ╥ ╥  ← spade connectors
        ┌─────╨─╨─────┐
        │    black     │  ← spades protrude 31.41mm
        │    coil      │    from one edge of black body
        │   housing    │
        │              │
   ┌────┴──────────────┴────┐
   │    white valve body     │ ← 32.71mm x 32.71mm square
   │   (2x2 mounting holes) │    (excluding collets/ports)
   └────────────────────────┘

   ▲ 56.04mm from mounting surface to furthest black body edge

SIDE VIEW (Y-Z plane, looking along width axis X):

         ┌───────┐
         │ black │  spade connectors
         │ coil  │  extend this way →  ╤═╤
         │       │                     │ │
    ┌────┴───────┴────┐
    │  white body      │
    ○──────────────────○ ← tube ports (Y axis)

    ◄── 56.00mm collet to collet (Y) ──►
```

### White Valve Body (Fluid Section)
- **Cross-section: 32.71mm x 32.71mm square** (caliper-verified, photo 03; user confirmed square)
- **Collet-to-collet distance (Y): 56.00mm** (caliper-verified, photo 01)
- The top face of the white body has a **raised circular diaphragm boss** — this is where the diaphragm chamber sits internally
- Two cylindrical QC port stubs with collets extend from opposite ends along the Y axis
- **2x2 mounting hole grid** on one face of the white body, with outer edge-to-edge dimension of **31.41mm** (caliper-verified, photo 04)

### Metal/Black Solenoid Coil Housing (Electrical Section)
- Rectangular case containing the electromagnetic coil
- Mounted on top of the valve body at its **center** (creating the T-shape)
- **Distance from white body mounting surface to furthest edge of black body: 56.04mm** (caliper-verified, photo 02)
- **Spade connector terminals:** Two blade-type electrical contacts protruding from the top of the housing. Spade protrusion measured from one edge of the black body to spade tips: **31.41mm** (caliper-verified, photo 05).

### Overall Assembly Envelope
- **Collet-to-collet (Y): 56.00mm** (caliper-verified, photo 01)
- **Mounting surface to black body edge (Z): 56.04mm** (caliper-verified, photo 02)
- **White body edge-to-edge (X and Y cross-section): 32.71mm square** (caliper-verified, photo 03)

## Caliper Measurements Summary

| Photo | Reading | What's Being Measured | Confidence |
|---|---|---|---|
| 01 | 56.00mm | Collet-to-collet distance along tube flow axis (Y) | HIGH (user-verified) |
| 02 | 56.04mm | Mounting surface on white body to furthest edge of black body (Z) | HIGH (user-verified) |
| 03 | 32.71mm | White body edge-to-edge, square cross-section, excluding collets/push-connects | HIGH (user-verified) |
| 04 | 31.41mm | 2x2 mounting hole grid, outermost edge-to-edge | HIGH (user-verified) |
| 05 | 31.41mm | Spade protrusion: one edge of black body to spade tips | HIGH (user-verified) |

## Comparison with Previous Estimates

| Dimension | Previous Estimate | Caliper-Verified | Notes |
|---|---|---|---|
| Width (X) | 34.0mm | **32.71mm** (white body, square) | Narrower than estimated; body is square |
| Depth (Y, collet-to-collet) | 63.5mm | **56.00mm** | Significantly shorter than estimated |
| Height (Z, mounting surface to black body edge) | 58.4mm | **56.04mm** | Close to estimate, slightly shorter |

## Mounting Considerations for Valve Rack Design

### 2x2 Mounting Hole Grid
The white valve body has a **2x2 grid of mounting holes** with an outer edge-to-edge dimension of **31.41mm** (photo 04). This provides a direct screw-mounting option.

### T-Shape Profile
The metal solenoid coil is centered on the white body, creating a symmetric T-profile from the front. A cradle must:
1. Support the white valve body from below and on the sides
2. Leave clearance above for the centered solenoid coil to rise vertically
3. Not interfere with tube ports (Y axis access) or spade connectors (top)

### Controlling Dimensions for Rack Slot Sizing
- **Slot width (X):** Must clear 32.71mm white body. Use ~34mm for light clearance.
- **Slot depth (Y):** Must accommodate 56mm collet-to-collet span, plus any additional port stub protrusion.
- **Slot height (Z):** 56.04mm from mounting surface to top of black body, plus spade protrusion above that.

### Port and Electrical Access
- **Tube ports:** Both ends of the Y axis must be accessible for push-to-connect tubing insertion/removal.
- **Spade connectors:** Top of assembly. Protrude 31.41mm from one edge of the black body.

## Geometry for 3D Modeling Agents

When modeling a valve rack cradle:

1. **The valve is T-shaped, not rectangular.** The white body is 32.71mm square (excluding ports/collets).
2. **White body is the primary mounting surface.** It has a 2x2 mounting hole grid (31.41mm edge-to-edge). Design around screw mounting or saddle clamping of the 32.71mm square body.
3. **Solenoid coil protrudes upward from the center** of the white body. 56.04mm from mounting surface to top of black body.
4. **Port stubs with collets protrude along Y.** Collet-to-collet is 56.00mm; port stubs may add length beyond this.
5. **Spade connectors protrude 31.41mm** from one edge of the black body.
6. **The T-profile is symmetric in X.** The valve can be cradled with a centered saddle.

## Remaining Unknowns

1. **Tube port stub OD and protrusion length** — not measured. Needed for tube routing clearance.
2. **Port center axis height** — distance from bottom of white body to the center of the tube ports. Needed for aligning tubes.
3. **Solenoid coil housing exact width and depth** — separate from overall envelope.
4. **Spade connector spacing** — needed for wiring harness design.
5. **Whether the ports are truly inline (coaxial)** — or slightly offset from each other.
6. **Mounting hole diameter and center-to-center spacing** — only edge-to-edge (31.41mm) measured so far.
7. **Diaphragm boss diameter** — visible from top but not measured.

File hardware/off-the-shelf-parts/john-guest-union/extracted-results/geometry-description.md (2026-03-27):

# John Guest PP0408W 1/4" Union — Caliper-Verified Geometry Description

## Purpose of This Document

This document describes the physical geometry of the John Guest PP0408W push-to-connect union fitting in enough detail that an agent generating engineering drawings or 3D-printable mounts can precisely model every surface, shoulder, and interface zone — without holding the part.

**Reference photographs:** Caliper photos of the physical fitting are in `../raw-images/`. Photo numbers referenced throughout this document (e.g., "photo 01") correspond to numbered files in that directory.

## Overall Form

The fitting is a **symmetric inline union**: a single white acetal copolymer body with identical tube-accepting ports on each end. It connects two pieces of 1/4" OD (6.35mm) tubing end-to-end through a straight-through internal passage. The fitting is rotationally symmetric about its long axis (axis of tube flow).

When viewed from the side, the profile is a **barbell**: two wider collet-ring sections (15.10mm OD) at each end, connected by a significantly narrower central body (9.31mm OD). This diameter step-down is critical for understanding how the fitting sits in pockets and how the release plate engages it.

## Axis Convention

- **Long axis (L):** The axis of tube flow, running through the center of both ports. All "length" dimensions are along this axis.
- **Radial (R):** Perpendicular to L. The fitting is axially symmetric — all cross-sections perpendicular to L are circles.

## Dimensional Profile — 5 Zones Along the Long Axis

The fitting has 5 distinct zones. Because the fitting is symmetric, only 3 unique zones exist. Described from left port inward:

```
  ┌──────┐              ┌──────┐
  │COLLET│  ┌────────┐  │COLLET│
  │15.10 │──│  9.31  │──│15.10 │
  │      │  │ center │  │      │
  │12.08 │  │ 12.16  │  │12.08 │
  └──────┘  └────────┘  └──────┘
  ◄─────── 36.32mm body ────────►
  ◄──── 39.13mm collets compressed ────►
  ◄───── 41.80mm collets extended ──────►
```

### Zone 1: Body End Section (left end)
- **OD: 15.10mm** (caliper-verified, photo 01) — this is the fixed housing that contains the collet mechanism
- **Length: 12.08mm** (caliper-verified)
- This section houses the internal collet mechanism: spring steel gripper teeth that grab the inserted tube, and the collet (release sleeve).
- The outer surface is smooth cylindrical white acetal.
- **End face:** Open circular port accepting 1/4" OD (6.35mm nominal / 6.30mm caliper-measured) tubing.
- End-on view of body end OD: **14.96mm** (photos 02, 03) — slight measurement variation from photo 01, likely parallax. Use 15.10mm as the controlling dimension.
- **Collet (release sleeve):** The visible moving ring at the end face that the user pushes inward to release the tube. This is the part the release plate must engage.
  - **Collet OD: 9.57mm** (caliper-verified, photos 04, 05)
  - **Collet wall thickness: 1.44mm** (caliper-verified)
  - **Collet ID: 6.69mm** (derived: 9.57 - 2×1.44 = 6.69mm) — the tube (6.30mm) passes through this opening with 0.39mm clearance
  - The collet protrudes from the body end face and translates axially inward when pushed
- **Blue variant:** Some PP0408W units include a blue plastic collet (visible in photo 08). Same mechanism and dimensions.

### Zone 2: Shoulder / Step-Down
- Sharp transition from 15.10mm body end OD to 9.31mm central body.
- This shoulder is a **radial face** — a flat annular ring perpendicular to the long axis.
- **Shoulder annular width:** (15.10 - 9.31) / 2 = **2.90mm** per side.
- These shoulders provide axial location when the center body sits in a pocket bore.

### Zone 3: Central Body
- **OD: 9.31mm** (caliper-verified, photo 06)
- **Length: 12.16mm** (caliper-verified)
- Smooth cylindrical section — the narrowest part of the fitting.
- This is the section that press-fits into the cartridge rear wall pocket. A **9.8mm bore** would give a sliding fit; a **9.5mm bore** would give a light press-fit.

### Zone 4 & 5: Mirror of Zones 2 & 1
Identical shoulder and body end on the opposite end.

## Overall Length Measurements

| Measurement | Value | What It Represents |
|---|---|---|
| Body without collets | 36.32mm | Sum of 12.08 + 12.16 + 12.08 (just the 3 solid body zones) |
| Collets compressed | 39.13mm | Full length with collet sleeves pushed fully inward (photo 07) |
| Collets extended | 41.80mm | Full length with collet sleeves in default/extended position (photo 08, blue ring visible) |
| Collet protrusion (total, both ends) | 39.13 - 36.32 = **2.81mm** | ~1.4mm per side when compressed |
| Collet travel (total, both ends) | 41.80 - 39.13 = **2.67mm** | ~1.3mm per side from extended to compressed |

## Caliper Measurements Summary

| Photo | Reading | What's Being Measured | Confidence |
|---|---|---|---|
| 01 | 15.10mm | Collet ring OD, side view | HIGH |
| 02 | 14.96mm | Collet ring OD, end-on view | HIGH |
| 03 | 14.96mm | Collet ring OD, side angle (confirms 02) | HIGH |
| 04 | 9.57mm | Collet (release sleeve) OD, end-on | HIGH |
| 05 | 9.57mm | Same as 04, different angle | HIGH |
| 06 | 9.31mm | Central body OD (the narrow waist) | HIGH |
| 07 | 39.13mm | Overall length, collets compressed | HIGH |
| 08 | 41.80mm | Overall length, collets extended (blue ring visible) | HIGH |

## Corrections to Previous parts.md Values

| Parameter | Old Value | Corrected Value | Impact |
|---|---|---|---|
| Body OD | 12.7mm | **9.31mm** (center body), **15.10mm** (body ends) | Rear wall pocket bore must match 9.31mm center body, NOT 12.7mm. Current 13.0mm bore is too large for press-fit of 9.31mm body. |
| Overall length | 38.1mm | **39.13mm** (compressed) / **41.80mm** (extended) | Slightly longer than spec |
| Body end OD | ~12.7mm | **15.10mm** | Release plate outer bore must clear 15.10mm, not 12.7mm |
| Collet travel | TBD | **~1.3mm per side** (2.67mm total) | Release plate stroke of 3mm is more than sufficient |
| Collet OD | not measured | **9.57mm** | The moving release sleeve; release plate inner lip must hug this |
| Collet wall | not measured | **1.44mm** | Collet ID = 6.69mm; tube (6.30mm) passes through |

## Critical Design Implications

### Rear Wall Pocket Bore
The fitting's barbell profile means the pocket bore design is fundamentally different than assumed:
- **Option A (pocket grips center body):** Bore = ~9.5–9.8mm. The body ends (15.10mm) protrude on both sides of the wall. The wall pocket is narrow but the grip is on the skinny section.
- **Option B (pocket clears body end):** Bore = ~15.5mm. The fitting slides through freely and must be retained by other means (snap ring, adhesive, interference on collet shoulder).
- **The current design assumed a uniform ~12.7mm cylinder — this must be redesigned** for the actual barbell profile.

### Release Plate Stepped Bores
Updated bore design based on caliper-verified collet dimensions (collet OD 9.57mm, wall 1.44mm, ID 6.69mm):
- **Tube clearance hole:** Must be between 6.30mm (tube OD) and 6.69mm (collet ID) — only 0.39mm design window. The plate face around this bore contacts the collet's annular end face (from collet ID 6.69mm to collet OD 9.57mm = full 1.44mm wall contact).
- **Inner lip (collet hugger):** Just over 9.57mm collet OD, as tight as manufacturing allows. This bore closely surrounds the collet for lateral constraint, preventing wobble during release — the same principle as the PI-TOOL's outer cradle but at the collet scale.
- **Outer bore (body end cradle):** Just over 15.10mm body end OD, as tight as manufacturing allows.

### Release Mechanism Stroke
The collet travel is ~1.3mm per side. The cam lever produces 3mm of plate travel. This means the release mechanism has ~1.7mm of margin — comfortable, but the plate must contact the body end before the stroke begins (i.e., the fitting must be seated so the body end is within reach of the plate's starting position).

## Geometry for 3D Modeling Agents

When modeling parts that interface with this fitting:

1. **The fitting is a barbell, not a cylinder.** Any pocket, bore, or clamp must account for the 15.10mm → 9.31mm → 15.10mm profile.
2. **Press-fit on the 9.31mm center body** is the natural mounting strategy. The shoulders provide axial location.
3. **Body end sections protrude at 15.10mm OD** — ensure clearance or intentional engagement (for release plate).
4. **The collet is the moving part (9.57mm OD, 1.44mm wall, 6.69mm ID).** The release plate pushes on the collet's annular end face. The plate's through-hole must be between 6.30mm (tube) and 6.69mm (collet ID) to contact the face. The inner lip must be just over 9.57mm to hug the collet for lateral constraint.
5. **Tube insertion depth:** ~16mm per side (industry standard, not directly measured here). Plan for 6.35mm (nominal) / 6.30mm (measured) tube protruding ~16mm into each end.
6. **Total axial footprint:** 42mm with collets extended, 39mm compressed, plus tube insertion lengths on each side.

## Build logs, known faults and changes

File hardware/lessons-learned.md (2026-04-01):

I have the full picture now. Here's what I see:

---

## What happened

**Phase 1: The Pipeline Era** — You built an elaborate multi-agent pipeline to get AI to produce STEP files autonomously. An orchestrator would launch an engineering manager, which would write a parts spec, then write a CadQuery script, then run it. There were rubrics, validation checks, feature traceability requirements, multiple roles (orchestrator, engineering manager, build planner). The pipeline went through many iterations itself — you added grounding rules, path continuity probes, synthesis constraints, scoping principles. All of this was scaffolding to try to get the AI to produce correct geometry *without you understanding the geometry yourself*.

**Phase 2: Frustration** — Commit messages like `"WHY IS THIS SO HARD FOR THEM?"`, `"Ugh"`, `"Why don't they commit anything?!"`, `"Remove features that were not actually functional and were just the AI confused trying to ambitiously implement more rails it did not understand at all"`. The AI kept adding features that weren't asked for, getting confused about what rails do, producing geometry that was wrong in ways that were hard to catch without inspecting the STEP file yourself. The coupler tray split — conceptually simple (cut a plate in half through the hole centers) — took multiple attempts and corrections.

**Phase 3: Pipeline Teardown** — Around 7:20 PM on March 30, you ripped out the pipeline. Merged the engineering manager into the orchestrator, deleted `pipeline.md`, flattened the steps folder, removed the research phase. Then at 9:47 PM, you removed the confused features the AI had added to the left wall.

**Phase 4: You Learned CadQuery** — Starting at commit `9339de2e` (9:49 PM March 30), something fundamentally changed. The commits are no longer "AI produces a part from a spec." They're surgical: "Allow front plate and back plate to be inserted — removing blockers that prevented insertion." You're reading the CadQuery scripts, understanding what `PASS_THRU_GAP` means, knowing that `lip_bottom_b` needs to start at `PASS_THRU_GAP` instead of `0.0` so that panels can physically slide past each other during assembly. Every commit from this point forward is a precise, small, correct change — because **you know what the code does**.

**Phase 5: AI as Typist, Not Designer** — The commits still say `Co-Authored-By: Claude Opus 4.6`, so you're still using AI. But the nature of the collaboration flipped. You're telling the AI *exactly* what to change: "widen to 170mm, shift features +15mm, move strut bores outward." The AI is executing precise instructions in a framework you now understand. It's not designing — it's typing.

---

## What you discovered

The pipeline was trying to solve the wrong problem. The issue was never "how do we get AI to produce valid CadQuery." The AI can produce valid CadQuery just fine — it passes all the validation checks. The problem is that **the AI doesn't understand what it's building**. It can't visualize the physical object. It doesn't know that two lips forming a channel need a gap at the intersection where another panel slides through. It doesn't know that a diamond cutout better matches a pump base than a circle. It adds "plate bottom rails" that overlap an existing rail because it's pattern-matching on "rails = good" without understanding why each rail exists.

No amount of pipeline scaffolding, rubrics, or validation checks can substitute for spatial understanding. The validation checks confirm the geometry *is what the script says it is* — but they can't confirm *the script describes something that makes physical sense*.

What works is: **you** understand the part, **you** decide what the geometry should be, and then you tell the AI to implement that specific geometry in CadQuery. The AI is an excellent CadQuery typist. It is not a mechanical designer.

The pipeline wasn't useless — it got the initial simple parts made (flat plates with holes). But the moment the parts needed to *relate to each other* in physical space (rails that panels slide through, cutouts that let one part pass another), the AI hit a wall. And no amount of documentation, rules, or agent orchestration could get it past that wall. You had to cross it yourself.

*(Background task completed — the pipeline.md history search I already used above.)*

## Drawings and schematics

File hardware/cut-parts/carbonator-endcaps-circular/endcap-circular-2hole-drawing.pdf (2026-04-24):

## CARBONATOR END CAP — CIRCULAR, 2-HOLE NPT

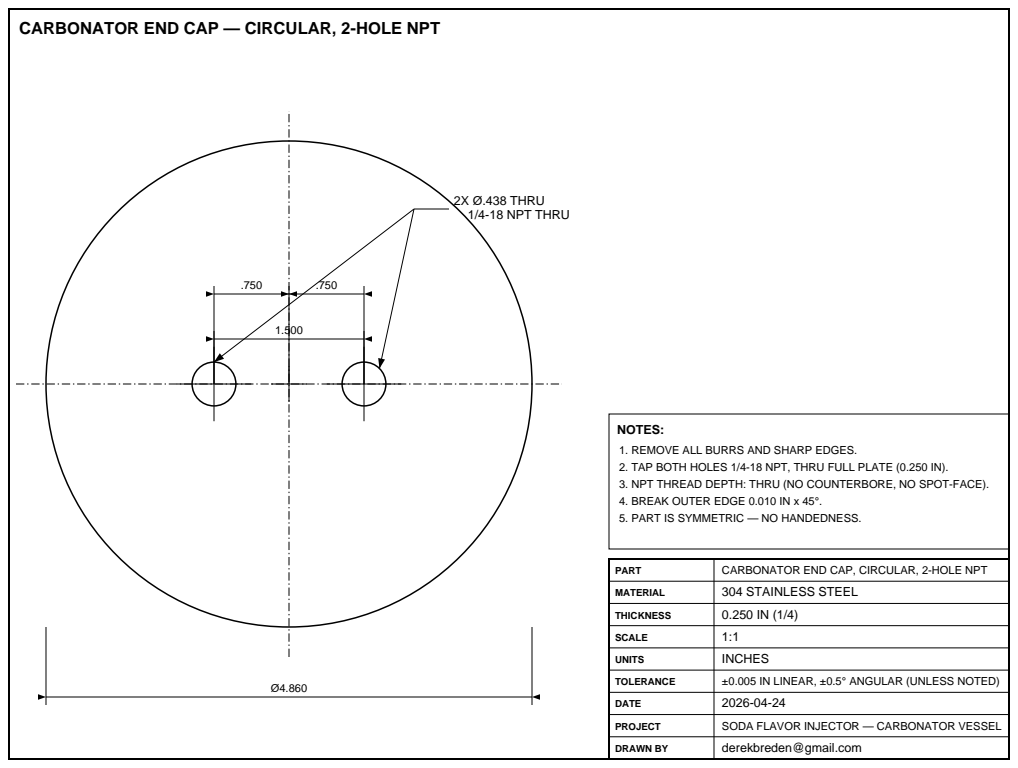
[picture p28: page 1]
2X Ø.438 THRU 1/4-18 NPT THRU; PART; CARBONATOR END CAP, CIRCULAR, 2-HOLE NPT; MATERIAL; 304 STAINLESS STEEL; THICKNESS; SCALE; UNITS; INCHES; TOLERANCE; ±0.005 IN LINEAR, ±0.5° ANGULAR (UNLESS NOTED); DATE; PROJECT; SODA FLAVOR INJECTOR — CARBONATOR VESSEL; DRAWN BY; derekbreden@gmail.com

NOTES:
1. REMOVE ALL BURRS AND SHARP EDGES.
2. TAP BOTH HOLES 1/4-18 NPT, THRU FULL PLATE (0.250 IN).
3. NPT THREAD DEPTH: THRU (NO COUNTERBORE, NO SPOT-FACE).
4. BREAK OUTER EDGE 0.010 IN x 45°.
5. PART IS SYMMETRIC — NO HANDEDNESS.

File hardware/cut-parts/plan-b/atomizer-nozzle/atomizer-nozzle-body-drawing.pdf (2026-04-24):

## ATOMIZER NOZZLE — BODY (316L SS, 2-PIECE ASSEMBLY) 15.65

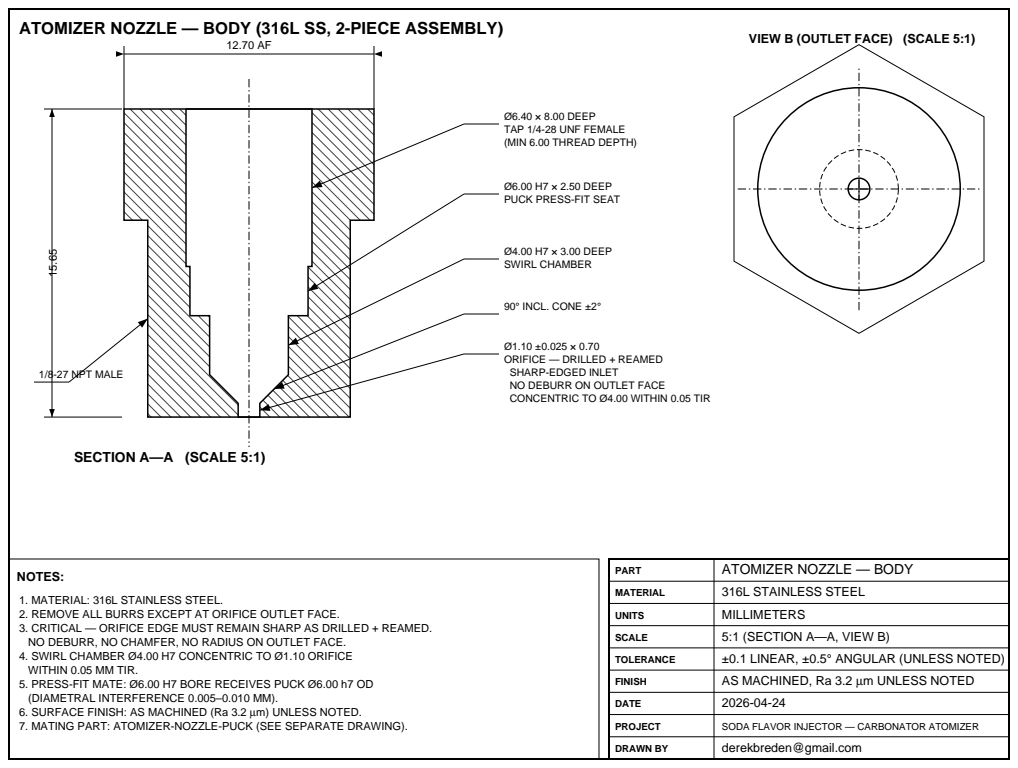
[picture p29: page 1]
Ø4.00 H7 × 3.00 DEEP SWIRL CHAMBER; 90° INCL. CONE ±2°; 1/8-27 NPT MALE; SECTION A—A (SCALE 5:1); PART; ATOMIZER NOZZLE — BODY; MATERIAL; 316L STAINLESS STEEL; UNITS; MILLIMETERS; SCALE; 5:1 (SECTION A—A, VIEW B); TOLERANCE; ±0.1 LINEAR, ±0.5° ANGULAR (UNLESS NOTED); FINISH; AS MACHINED, Ra 3.2 µm UNLESS NOTED; DATE; PROJECT; SODA FLAVOR INJECTOR — CARBONATOR ATOMIZER; DRAWN BY; derekbreden@gmail.com

VIEW B (OUTLET FACE) (SCALE 5:1)

Ø6.40 × 8.00 DEEP
TAP 1/4-28 UNF FEMALE
(MIN 6.00 THREAD DEPTH)

Ø6.00 H7 × 2.50 DEEP
PUCK PRESS-FIT SEAT

ORIFICE — DRILLED + REAMED
SHARP-EDGED INLET
NO DEBURR ON OUTLET FACE
CONCENTRIC TO Ø4.00 WITHIN 0.05 TIR

NOTES:
1. MATERIAL: 316L STAINLESS STEEL.
2. REMOVE ALL BURRS EXCEPT AT ORIFICE OUTLET FACE.
3. CRITICAL — ORIFICE EDGE MUST REMAIN SHARP AS DRILLED + REAMED.
NO DEBURR, NO CHAMFER, NO RADIUS ON OUTLET FACE.
4. SWIRL CHAMBER Ø4.00 H7 CONCENTRIC TO Ø1.10 ORIFICE
WITHIN 0.05 MM TIR.
5. PRESS-FIT MATE: Ø6.00 H7 BORE RECEIVES PUCK Ø6.00 h7 OD
(DIAMETRAL INTERFERENCE 0.005–0.010 MM).
6. SURFACE FINISH: AS MACHINED (Ra 3.2 µm) UNLESS NOTED.
7. MATING PART: ATOMIZER-NOZZLE-PUCK (SEE SEPARATE DRAWING).

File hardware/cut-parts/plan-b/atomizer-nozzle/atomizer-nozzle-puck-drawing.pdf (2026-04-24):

## ATOMIZER NOZZLE — PUCK (316L SS, SWIRL DISTRIBUTOR)

### FRONT FACE VIEW (SCALE 10:1)

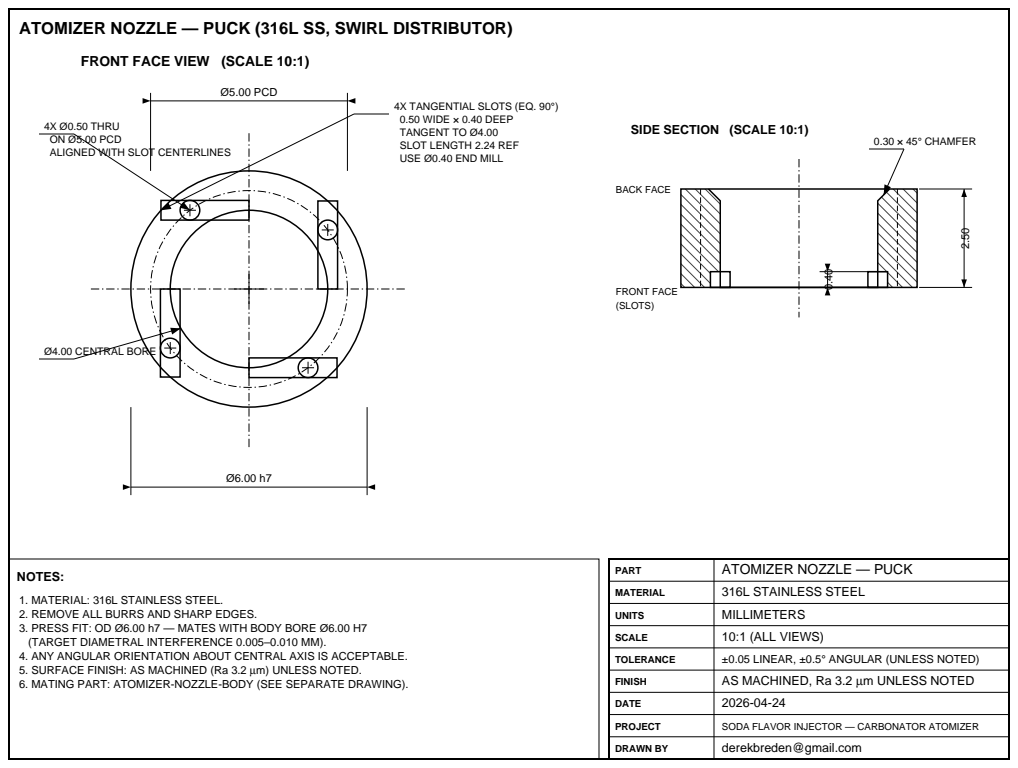
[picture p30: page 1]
Ø4.00 CENTRAL BORE; Ø5.00 PCD; 0.30 × 45° CHAMFER; BACK FACE; FRONT FACE (SLOTS); PART; ATOMIZER NOZZLE — PUCK; MATERIAL; 316L STAINLESS STEEL; UNITS; MILLIMETERS; SCALE; 10:1 (ALL VIEWS); TOLERANCE; ±0.05 LINEAR, ±0.5° ANGULAR (UNLESS NOTED); FINISH; AS MACHINED, Ra 3.2 µm UNLESS NOTED; DATE; PROJECT; SODA FLAVOR INJECTOR — CARBONATOR ATOMIZER; DRAWN BY; derekbreden@gmail.com

4X TANGENTIAL SLOTS (EQ. 90°)
0.50 WIDE × 0.40 DEEP
TANGENT TO Ø4.00
SLOT LENGTH 2.24 REF
USE Ø0.40 END MILL

4X Ø0.50 THRU
ON Ø5.00 PCD
ALIGNED WITH SLOT CENTERLINES

SIDE SECTION (SCALE 10:1)

NOTES:
1. MATERIAL: 316L STAINLESS STEEL.
2. REMOVE ALL BURRS AND SHARP EDGES.
3. PRESS FIT: OD Ø6.00 h7 — MATES WITH BODY BORE Ø6.00 H7
(TARGET DIAMETRAL INTERFERENCE 0.005–0.010 MM).
4. ANY ANGULAR ORIENTATION ABOUT CENTRAL AXIS IS ACCEPTABLE.
5. SURFACE FINISH: AS MACHINED (Ra 3.2 µm) UNLESS NOTED.
6. MATING PART: ATOMIZER-NOZZLE-BODY (SEE SEPARATE DRAWING).

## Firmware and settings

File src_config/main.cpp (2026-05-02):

#include <Arduino.h>
#include <esp_system.h>
#include <Arduino_GFX_Library.h>
#include <lvgl.h>
#include <LittleFS.h>
#include <NimBLEDevice.h>
#include "host/ble_hs_mbuf.h"
#include "host/ble_gatt.h"
#include <PersistentLog.h>
#include <proto_link.h>
#include "CST816D.h"
#include "font_ratio_64.h"
#include "fw_version.h"

// Seed images (compiled in for first-boot only, then served from LittleFS)
#include "images/flavor0_240.h"
#include "images/flavor1_240.h"
#include "images/flavor2_240.h"
// Animation frames (compiled in for screensaver idle animation)
#include "images/anim_00.h"
#include "images/anim_01.h"
#include "images/anim_02.h"
#include "images/anim_03.h"
#include "images/anim_04.h"
#include "images/anim_05.h"
#include "images/anim_06.h"
#include "images/anim_07.h"
#include "images/anim_08.h"
#include "images/anim_09.h"
#include "images/anim_10.h"
#include "images/anim_11.h"
#include "images/anim_12.h"
#include "images/anim_13.h"
#include "images/anim_14.h"
#include "images/anim_15.h"

static const uint16_t *animFrames[] = {
    anim_00, anim_01, anim_02, anim_03,
    anim_04, anim_05, anim_06, anim_07,
    anim_08, anim_09, anim_10, anim_11,
    anim_12, anim_13, anim_14, anim_15,
};
static const uint8_t NUM_ANIM_FRAMES = 16;

// ════════════════════════════════════════════════════════════
//  ESP32-S3 Config Display — Soda Flavor Injector
// ════════════════════════════════════════════════════════════

// ── Theme colors (match iOS app / app icon) ──
#define THEME_BG           lv_color_hex(0x1a1a2e)
#define THEME_BG_RGB565    0x18C5
#define THEME_TEXT_PRIMARY  lv_color_white()
#define THEME_TEXT_SECONDARY lv_color_hex(0x999999)
#define THEME_TEXT_INACTIVE lv_color_hex(0x505058)
#define THEME_DOT_ACTIVE   lv_color_white()
#define THEME_DOT_INACTIVE lv_color_hex(0x3a3a46)
#define THEME_ALERT        lv_color_hex(0xFF4444)
// Pin assignments for Meshnology ESP32-S3 1.28" Round Rotary Display

// ── Display SPI (GC9A01A, 240x240) ──
#define TFT_BLK  46
#define TFT_RST  14
#define TFT_CS    9
#define TFT_MOSI 11
#define TFT_SCLK 10
#define TFT_DC    3

// ── Board power pins (Meshnology hardware requirement) ──
#define PWR_EN   40
#define PWR_3V3   1
#define PWR_VBUS  2

// ── Rotary Encoder ──
#define ENCODER_CLK 45
#define ENCODER_DT  42

// ── Touch (CST816D) ──
#define TOUCH_SDA  6
#define TOUCH_SCL  7
#define TOUCH_INT  5
#define TOUCH_RST 13

// ── Image constants ──
#define S3_SCREEN_W   240
#define S3_SCREEN_H   240
#define IMAGE_BYTES   (S3_SCREEN_W * S3_SCREEN_H * 2)  // 115200

#define META_PATH     "/meta.txt"
#define LABELS_PATH   "/labels.txt"
#define CRCS_PATH     "/img_crcs.txt"
#define MAX_IMAGES    10
#define MAX_LABEL_LEN 32
#define MAX_CHUNK_SIZE 128

// ── Persistent log (survives reboots, ring buffer on LittleFS) ──
PersistentLog plog(LittleFS, "/logs/system.log", 16384);  // 16KB budget (smaller flash)

static uint8_t numImages = 0;
static char labels[MAX_IMAGES][MAX_LABEL_LEN + 1];
static uint32_t localS3Crcs[MAX_IMAGES];   // per-image CRC-32 for S3 RGB565
static uint32_t localPngCrcs[MAX_IMAGES];  // per-image CRC-32 for PNG
// Shared between BLE upload (phone → S3) and display rendering. Anything that
// writes to imageBuf must check bleUpload.phase == BLE_UP_IDLE first, or it
// will clobber an in-flight upload (see loadImageFromFS guard below).
static uint16_t *imageBuf = nullptr;       // allocated in PSRAM at setup()

// ── Config state (synced from ESP32 via UART) ──
uint8_t flavor1Image = 0;
uint8_t flavor2Image = 1;
uint8_t flavor1Ratio = 20;
uint8_t flavor2Ratio = 20;
bool configSynced = false;
unsigned long lastGetConfig = 0;

// ── Hardware objects ──
Arduino_ESP32SPI *spi_bus = new Arduino_ESP32SPI(TFT_DC, TFT_CS, TFT_SCLK, TFT_MOSI, GFX_NOT_DEFINED, FSPI, true);
Arduino_GC9A01 *hw_display = new Arduino_GC9A01(spi_bus, TFT_RST, 0, true);
CST816D touch(TOUCH_SDA, TOUCH_SCL, TOUCH_RST, TOUCH_INT);

// ── LVGL display buffer ──
static lv_disp_draw_buf_t draw_buf;
static lv_color_t *lvgl_buf;

// ── UART to ESP32 (Serial0 = UART0, J34 connector) ──
ProtoLink proto;  // TinyProto HDLC link to ESP32

// ── BLE (GATT/NUS via NimBLE-Arduino) ──
#define NUS_SERVICE_UUID "6E400001-B5A3-F393-E0A9-E50E24DCCA9E"
#define NUS_RX_UUID      "6E400002-B5A3-F393-E0A9-E50E24DCCA9E"
#define NUS_TX_UUID      "6E400003-B5A3-F393-E0A9-E50E24DCCA9E"

static NimBLEServer *pBLEServer = nullptr;
static NimBLECharacteristic *pTxChar = nullptr;

static bool bleHasClients() {
  return pBLEServer && pBLEServer->getConnectedCount() > 0;
}

// Forward declarations
static void bleSendFrame(uint8_t type, const uint8_t *payload, uint16_t len);
static void bleSendText(const char *text);
static void bleSendFrameTo(uint16_t connHandle, uint8_t type,
                           const uint8_t *payload, uint16_t len);
static void bleSendTextTo(uint16_t connHandle, const char *text);
static bool loadImageFromFS(uint8_t slot);
static void imagePath(char *buf, uint8_t slot);
static void updateMeta();
static void saveCrcs();

// BLE frame types (GATT/NUS wire format: [type(1B)] [len(2B LE)] [payload...])
#define BLE_FRAME_TEXT      0x01
#define BLE_FRAME_BIN_START 0x02
#define BLE_FRAME_BIN_DATA  0x03
#define BLE_FRAME_BIN_END   0x04

// ── BLE image download state ──
// Streams directly from LittleFS file — no imageBuf aliasing.
static bool bleImageSending = false;
static uint8_t bleImageSlot = 0;
static uint32_t bleImageSize = 0;
static uint32_t bleImageCrc = 0;
static File bleFile;
static uint8_t bleSendChunkBuf[256];

// ── BLE cross-task safety ──
// BLE RX callback runs on NimBLE task — must not do LittleFS I/O or Serial0
// writes directly. Instead, callback sets a request + buffers data, and loop()
// processes it on the main task.
enum BleRequest { BLE_REQ_NONE, BLE_REQ_LIST, BLE_REQ_GETPNG, BLE_REQ_GETIMG,
                  BLE_REQ_GET_CONFIG, BLE_REQ_GET_VERSION };
static volatile BleRequest bleRequest = BLE_REQ_NONE;
static volatile int bleRequestSlot = -1;
static volatile uint16_t bleRequestConnHandle = 0;

// Per-client ownership tracking for image transfers
static uint16_t bleImageSendConnHandle = 0;
static uint16_t bleUploadConnHandle = 0;

// Ring buffer for BLE→ESP32 text command forwarding
#define BLE_FWD_QUEUE_SIZE 8
#define BLE_FWD_BUF_LEN    64
static char bleFwdQueue[BLE_FWD_QUEUE_SIZE][BLE_FWD_BUF_LEN];
static volatile uint8_t bleFwdHead = 0;  // next write position (NimBLE task)
static volatile uint8_t bleFwdTail = 0;  // next read position (main task)

// ── BLE upload state (phone → S3, accumulated in imageBuf) ──
enum BleUploadPhase { BLE_UP_IDLE, BLE_UP_WAIT_DATA, BLE_UP_RECEIVED, BLE_UP_FORWARDING, BLE_UP_ESP_FORWARDING };
static struct {
  volatile BleUploadPhase phase = BLE_UP_IDLE;
  uint8_t  slot;
  uint8_t  fileType;      // 0=png, 1=s3_rgb, 2=rp_rgb
  uint32_t expectedSize;
  uint32_t expectedCrc32;
  volatile uint32_t receivedBytes;
  char     label[MAX_LABEL_LEN + 1];
  bool     hasLabel;
  unsigned long lastDataTime;
  volatile bool abortRequested = false;
  uint32_t chunkCount;
} bleUpload;

static void cleanupAbortedUpload(uint8_t slot);  // forward decl (used in disconnect + RX handlers)

// BLE disconnect cleanup (called from BLEServerCB::onDisconnect)
static void bleOnDisconnect(uint16_t connHandle) {
  Serial.printf("BLE: disconnected connHandle=%d (heap=%lu)\n",
                connHandle, (unsigned long)ESP.getFreeHeap());
  if (bleImageSending && connHandle == bleImageSendConnHandle) {
    bleImageSending = false;
    if (bleFile) bleFile.close();
    Serial.println("BLE: aborted image send (owner disconnected)");
  }
  if (bleUpload.phase != BLE_UP_IDLE && connHandle == bleUploadConnHandle) {
    if (bleUpload.phase == BLE_UP_FORWARDING || bleUpload.phase == BLE_UP_ESP_FORWARDING) {
      bleUpload.abortRequested = true;
    } else {
      cleanupAbortedUpload(bleUpload.slot);
      bleUpload.phase = BLE_UP_IDLE;
    }
    Serial.println("BLE: aborted upload (owner disconnected)");
  }
  if (!bleHasClients()) proto.sendText("BLE_DISCONNECTED");
}

static void bleImageSendChunks() {
  if (!bleImageSending || !bleHasClients() || !bleImageSendConnHandle) return;

  uint16_t ch = bleImageSendConnHandle;

  if (!bleFile || !bleFile.available()) {
    if (bleFile) bleFile.close();
    bleSendFrameTo(ch, BLE_FRAME_BIN_END, nullptr, 0);
    bleImageSending = false;
    Serial.printf("BLE image %d send complete (%u bytes)\n", bleImageSlot, bleImageSize);
    return;
  }

  // Send one chunk per loop iteration with delay for GATT flow control
  size_t n = bleFile.read(bleSendChunkBuf, 180);
  if (n > 0) {
    bleSendFrameTo(ch, BLE_FRAME_BIN_DATA, bleSendChunkBuf, n);
    delay(20);
  }
}

static uint32_t computeFileCrc(File &f) {
  uint32_t crc = 0;
  uint8_t buf[256];
  f.seek(0);
  while (f.available()) {
    size_t n = f.read(buf, sizeof(buf));
    crc = uartCrc32Update(crc, buf, n);
  }
  f.seek(0);
  return crc;
}

static bool openPngForBLE(uint8_t slot) {
  char path[24];
  snprintf(path, sizeof(path), "/s3_png%02d.png", slot);
  if (!LittleFS.exists(path)) {
    Serial.printf("loadPng: %s does not exist\n", path);
    return false;
  }
  bleFile = LittleFS.open(path, "r");
  if (!bleFile) {
    Serial.printf("loadPng: %s open failed\n", path);
    return false;
  }
  uint32_t size = bleFile.size();
  if (size == 0 || size > IMAGE_BYTES) {
    Serial.printf("loadPng: %s bad size %u\n", path, size);
    bleFile.close();
    return false;
  }
  bleImageSize = size;
  bleImageCrc = computeFileCrc(bleFile);
  Serial.printf("Opened PNG slot %d for BLE: %u bytes, CRC=0x%08lX\n", slot, size, (unsigned long)bleImageCrc);
  return true;
}

// BLE RX characteristic callback (runs on NimBLE task — defer I/O to main loop)
// Wire format: [type(1B)] [len(2B LE)] [payload...]
class BLERxCB : public NimBLECharacteristicCallbacks {
  void onWrite(NimBLECharacteristic *pChar, NimBLEConnInfo &connInfo) override {
    uint16_t connHandle = connInfo.getConnHandle();
    NimBLEAttValue raw = pChar->getValue();
    if (raw.length() < 3) return;  // minimum: 1B type + 2B length

    const uint8_t *d = raw.data();
    uint8_t type = d[0];
    uint16_t payloadLen = d[1] | ((uint16_t)d[2] << 8);
    const uint8_t *payload = d + 3;

    switch (type) {
      case BLE_FRAME_TEXT: {
        char textBuf[256];
        size_t tLen = payloadLen < sizeof(textBuf) - 1 ? payloadLen : sizeof(textBuf) - 1;
        memcpy(textBuf, payload, tLen);
        textBuf[tLen] = '\0';

        // ABORT_UPLOAD: handle immediately on NimBLE task
        if (strcmp(textBuf, "ABORT_UPLOAD") == 0) {
          bleUpload.abortRequested = true;
          if (bleUpload.phase == BLE_UP_WAIT_DATA || bleUpload.phase == BLE_UP_RECEIVED) {
            cleanupAbortedUpload(bleUpload.slot);
            bleUpload.phase = BLE_UP_IDLE;
            bleUpload.abortRequested = false;
          }
          bleSendTextTo(connHandle, "OK:UPLOAD_ABORTED");
          break;
        }

        if (strcmp(textBuf, "GET_CONFIG") == 0) {
          if (bleRequest != BLE_REQ_NONE) return;
          bleRequestConnHandle = connHandle;
          bleRequest = BLE_REQ_GET_CONFIG;
        } else if (strcmp(textBuf, "GET_VERSION") == 0) {
          if (bleRequest != BLE_REQ_NONE) return;
          bleRequestConnHandle = connHandle;
          bleRequest = BLE_REQ_GET_VERSION;
        } else if (strcmp(textBuf, "LIST") == 0) {
          if (bleRequest != BLE_REQ_NONE) return;
          bleRequestConnHandle = connHandle;
          bleRequest = BLE_REQ_LIST;
        } else if (strncmp(textBuf, "GETPNG:", 7) == 0) {
          if (bleRequest != BLE_REQ_NONE) return;
          bleRequestConnHandle = connHandle;
          bleRequestSlot = atoi(textBuf + 7);
          bleRequest = BLE_REQ_GETPNG;
        } else if (strncmp(textBuf, "GETIMG:", 7) == 0) {
          if (bleRequest != BLE_REQ_NONE) return;
          bleRequestConnHandle = connHandle;
          bleRequestSlot = atoi(textBuf + 7);
          bleRequest = BLE_REQ_GETIMG;
        } else {
          uint8_t nextHead = (bleFwdHead + 1) % BLE_FWD_QUEUE_SIZE;
          if (nextHead != bleFwdTail) {
            strncpy(bleFwdQueue[bleFwdHead], textBuf, BLE_FWD_BUF_LEN - 1);
            bleFwdQueue[bleFwdHead][BLE_FWD_BUF_LEN - 1] = '\0';
            __sync_synchronize();
            bleFwdHead = nextHead;
          }
        }
        break;
      }

      case BLE_FRAME_BIN_START: {
        if (payloadLen < 10) return;
        uint8_t slot = payload[0];
        uint8_t fileType = payload[1];
        uint32_t size = payload[2] | ((uint32_t)payload[3] << 8) |
                        ((uint32_t)payload[4] << 16) | ((uint32_t)payload[5] << 24);
        uint32_t crc = payload[6] | ((uint32_t)payload[7] << 8) |
                       ((uint32_t)payload[8] << 16) | ((uint32_t)payload[9] << 24);

        if (slot >= MAX_IMAGES || size == 0 || size > IMAGE_BYTES) {
          bleSendTextTo(connHandle, "IMG_ERR:INVALID_PARAMS");
          return;
        }
        if (bleImageSending || bleUpload.phase != BLE_UP_IDLE) {
          bleSendTextTo(connHandle, "IMG_ERR:BUSY");
          return;
        }

        bleUploadConnHandle = connHandle;
        bleUpload.slot = slot;
        bleUpload.fileType = fileType;
        bleUpload.expectedSize = size;
        bleUpload.expectedCrc32 = crc;
        bleUpload.receivedBytes = 0;
        bleUpload.hasLabel = false;
        bleUpload.abortRequested = false;
        bleUpload.chunkCount = 0;

        if (payloadLen > 10) {
          size_t lblLen = payloadLen - 10;
          if (lblLen > MAX_LABEL_LEN) lblLen = MAX_LABEL_LEN;
          memcpy(bleUpload.label, payload + 10, lblLen);
          bleUpload.label[lblLen] = '\0';
          bleUpload.hasLabel = true;
        }

        bleUpload.lastDataTime = millis();
        bleUpload.phase = BLE_UP_WAIT_DATA;
        Serial.printf("BLE upload: slot %d type %d size %lu\n",
                      slot, fileType, (unsigned long)size);
        break;
      }

      case BLE_FRAME_BIN_DATA: {
        if (bleUpload.phase != BLE_UP_WAIT_DATA) return;
        if (connHandle != bleUploadConnHandle) return;
        uint32_t remaining = IMAGE_BYTES - bleUpload.receivedBytes;
        uint16_t dataLen = (payloadLen <= remaining) ? payloadLen : remaining;
        if (dataLen > 0) {
          memcpy(((uint8_t*)imageBuf) + bleUpload.receivedBytes, payload, dataLen);
          bleUpload.receivedBytes += dataLen;
          bleUpload.chunkCount++;
          // Log every 50th chunk for progress tracking
          if (bleUpload.chunkCount % 50 == 0) {
            Serial.printf("BLE chunk #%u: %lu/%lu bytes\n",
                          bleUpload.chunkCount, bleUpload.receivedBytes,
                          bleUpload.expectedSize);
          }
        }
        bleUpload.lastDataTime = millis();
        break;
      }

      case BLE_FRAME_BIN_END: {
        if (bleUpload.phase != BLE_UP_WAIT_DATA) return;
        if (connHandle != bleUploadConnHandle) return;
        bleUpload.phase = BLE_UP_RECEIVED;
        break;
      }
    }
  }
};
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
void loop() {
  // Boot sync: request config from ESP32 every 500ms until synced
  if (!configSynced && millis() - lastGetConfig > 500) {
    proto.sendText("GET_CONFIG");
    Serial.println("UART TX: GET_CONFIG (boot sync)");
    lastGetConfig = millis();
  }

  // Check for USB serial commands (debug/test)
  static char usbBuf[64];
  static uint8_t usbPos = 0;
  while (Serial.available()) {
    char c = Serial.read();
    if (c == '\n' || c == '\r') {
      if (usbPos > 0) {
        usbBuf[usbPos] = '\0';
        processTextLine(usbBuf);
        usbPos = 0;
      }
    } else if (usbPos < sizeof(usbBuf) - 1) {
      usbBuf[usbPos++] = c;
    }
  }

  // Service TinyProto link (RX + TX + upload timeout)
  serviceProtoLink();

  // Process BLE requests on main task (safe for LittleFS + Serial0)
  processBleRequest();
  processBleForwardQueue();

  // Process completed BLE uploads (verify CRC, write to LittleFS, forward)
  processBleUpload();
  processBleUploadForward();

  // Check for abort during async ESP32 forwarding
  if (bleUpload.phase == BLE_UP_ESP_FORWARDING && bleUpload.abortRequested) {
    s3FwdAbort = true;  // signal FreeRTOS task to abort
  }

  // BLE upload timeout (30s with no data)
  if (bleUpload.phase == BLE_UP_WAIT_DATA &&
      millis() - bleUpload.lastDataTime > 30000) {
    bleUpload.phase = BLE_UP_IDLE;
    bleSendTextTo(bleUploadConnHandle, "IMG_ERR:TIMEOUT");
    Serial.println("BLE upload timed out");
  }

  // BLE image streaming (non-blocking, sends a few chunks per loop)
  bleImageSendChunks();

  int dir = readEncoder();
  bool tapped = readTap();

  // Screensaver: activate after idle timeout
  if (dir != 0 || tapped) {
    lastInputTime = millis();
    if (screensaverActive) {
      // Wake: stop animation timer, return to first page in browse mode
      stopScreensaver();
      screensaverActive = false;
      menuIndex = 0;
      editing = false;
      inSettings = false;
      inAbout = false;
      settingsConfirm = false;
      inPrime = false;
      inPrimeHold = false;
      drawScreen();
      // Consume this input — don't pass through
      dir = 0;
      tapped = false;
    }
  } else if (!screensaverActive && millis() - lastInputTime > SCREENSAVER_TIMEOUT) {
    screensaverActive = true;
    drawScreen();
  }

  // ── Hold-to-prime: raw touch detection on hold screen ──
  if (inPrimeHold && primeHoldIndex == 1) {
    if (currentTouching && !primeHolding) {
      // Finger down → start prime
      primeHolding = true;
      char buf[16];
      snprintf(buf, sizeof(buf), "PRIME_START:%d", primeFlavor);
      proto.sendText(buf);
      lastPrimeTick = millis();
      drawScreen();
      tapped = false;  // consume tap so handleTap doesn't also fire
    } else if (!currentTouching && primeHolding) {
      // Finger up → stop prime
      primeHolding = false;
      primeActive = false;
      proto.sendText("PRIME_STOP");
      drawScreen();
      tapped = false;
    } else if (primeHolding && millis() - lastPrimeTick >= 500) {
      // Send keepalive tick
      proto.sendText("PRIME_TICK");
      lastPrimeTick = millis();
    }
    if (currentTouching) tapped = false;  // suppress taps while touching on hold screen
  }

  if (dir != 0) handleNavigation(dir);
  if (tapped) handleTap();

  // Periodic heap check (every 5 min) — detect slow leaks
  static unsigned long lastHeapLog = 0;
  if (millis() - lastHeapLog >= 300000) {
    lastHeapLog = millis();
    unsigned long heap = ESP.getFreeHeap();
    unsigned long minHeap = ESP.getMinFreeHeap();
    Serial.printf("DIAG: heap=%lu minHeap=%lu uptime=%lus\n",
                  heap, minHeap, millis() / 1000);
    plog.println("heap=%lu min=%lu up=%lus", heap, minHeap, millis() / 1000);
  }

  lv_timer_handler();
  delay(5);
}

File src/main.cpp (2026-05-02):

#include <Arduino.h>
#include <esp_system.h>
#include <Wire.h>
#include <RTClib.h>
#include <LittleFS.h>
#include <ArduinoJson.h>
#include <PersistentLog.h>
#include <proto_link.h>
#include <proto_msg.h>
#include "fw_version.h"

// ════════════════════════════════════════════════════════════
//  Dual-Flavor Soda Maker
// ════════════════════════════════════════════════════════════
//
// Prototype valve topology (2 dispense valves + 2 clean solenoids on
// L298N drivers). The integrated-appliance manifold is described in
// hardware/topology/fluid-topology.md and is not yet implemented here.

// ── L298N Board A (flavor 1) ──
#define A_ENA  33    // pump PWM
#define A_IN1  25    // pump direction
#define A_IN2  26    // pump direction
#define A_ENB  12    // dispensing solenoid valve

// ── L298N Board B (flavor 2) ──
#define B_ENA  19    // pump PWM
#define B_IN1  18    // pump direction
#define B_IN2   5    // pump direction
#define B_ENB   4    // dispensing solenoid valve

// ── L298N Board C (clean solenoids) ──
#define CLEAN_SOL1_PIN 27   // clean solenoid flavor 1, L298N #3 Channel A ENA
#define CLEAN_SOL2_PIN 17   // clean solenoid flavor 2, L298N #3 Channel B ENB

// ── Inputs ──
#define FLAVOR_SW_PIN   13   // latching toggle: flavor select (air switch)
#define FLOW_PIN        23   // flow meter pulse input

// ── Per-flavor config (runtime, persisted in LittleFS) ──
// Ratio: flavoring to water in 1:X. Lower = more flavor.
//   6  = maximum strength (traditional BIB, e.g. Coke syrup)
//  20  = tuned for SodaStream concentrates
//  24  = minimum strength (hard limit floor)
// Image: index into the RP2040's LittleFS image store
uint8_t numRpImages = 0;  // updated at boot via QUERY_COUNT to RP2040
uint8_t numS3Images = 0;  // updated at boot via QUERY_COUNT to S3

// ── Image store (ESP32 LittleFS — authoritative source) ──
#define RP2040_IMAGE_BYTES (128 * 115 * 2)   // 29440
#define S3_IMAGE_BYTES     (240 * 240 * 2)    // 115200
#define MAX_STORE_IMAGES   10
#define MAX_LABEL_LEN      32
#define ESP_META_PATH      "/meta.txt"
#define ESP_LABELS_PATH    "/labels.txt"
#define ESP_CRCS_PATH      "/img_crcs.txt"
#define FW_VERSION_PATH    "/fw_version.txt"
#define USER_CONFIG_PATH   "/user_config.txt"
#define FW_VERSION         FW_BUILD_TIME

// ── Persistent log (survives reboots, ring buffer on LittleFS) ──
PersistentLog plog(LittleFS, "/logs/system.log", 32768);  // 32KB budget

// Factory defaults JSON (embedded in firmware flash at build time)
extern const char factory_manifest_start[] asm("_binary_images_factory_manifest_json_start");

// USB binary store protocol constants (upload_image.py → ESP32 LittleFS)
#define CMD_UPLOAD_START  0x01
#define CMD_CHUNK_DATA    0x02
#define CMD_UPLOAD_DONE   0x03
#define RESP_READY        0x10
#define RESP_CHUNK_OK     0x11
#define RESP_UPLOAD_OK    0x12

uint8_t numEspImages = 0;
uint8_t factoryImageCount = 0;  // slots 0..factoryImageCount-1 are protected
char espLabels[MAX_STORE_IMAGES][MAX_LABEL_LEN + 1];

// Per-slot CRC-32 values: [slot][0=RP, 1=S3, 2=PNG]
uint32_t espCrcs[MAX_STORE_IMAGES][3];
#define CRC_IDX_RP  0
#define CRC_IDX_S3  1
#define CRC_IDX_PNG 2

// ── S3-initiated upload state (BLE phone → S3 → ESP32 via TinyProto) ──
enum S3UploadState { S3UP_IDLE, S3UP_RECEIVING, S3UP_WAITING_DONE };
static struct {
  S3UploadState state = S3UP_IDLE;
  uint8_t slot;
  uint8_t fileType;  // 0=s3_rgb, 1=png, 2=rp_rgb
  uint32_t expectedSize;
  uint32_t receivedBytes;
  uint32_t runningCrc32;
  unsigned long lastDataTime;
  File file;
} s3Upload;

uint8_t flavor1Ratio = 20;
uint8_t flavor2Ratio = 20;
uint8_t flavor1Image = 0;
uint8_t flavor2Image = 1;

// ── Display UART (ESP32 ↔ RP2040, bidirectional) ──
#define DISPLAY_TX_PIN          32     // UART TX to RP2040 display
#define DISPLAY_RX_PIN          35     // UART RX from RP2040 (input-only GPIO)
#define CONFIG_SEND_INTERVAL_MS 30000  // resend image mapping every 30s

// ── RP2040 link (TinyProto) ──
ProtoLink protoRP;

// ── S3 link (TinyProto) ──
ProtoLink protoS3;

// ── RP2040 command queue (simple FIFO for non-upload operations) ──
// Upload uses a dedicated FreeRTOS task; everything else goes through this queue.
#define RP_QUEUE_SIZE 16
#define RP_TEXT_MAX   200

enum RpQueueType : uint8_t { RQ_NONE, RQ_TEXT, RQ_DELETE, RQ_SWAP, RQ_QUERY };

// Callbacks for RP2040 async operations
typedef void (*RpUploadCb)(uint8_t slot, bool success);
typedef void (*RpDeleteCb)(uint8_t slot, bool success);
typedef void (*RpSwapCb)(uint8_t slotA, uint8_t slotB, bool success);
typedef void (*RpQueryCb)(uint8_t count, bool success);
typedef void (*RpTextCb)(const char *response);

struct RpQueueEntry {
  RpQueueType type = RQ_NONE;
  char text[RP_TEXT_MAX];
  uint8_t slot;
  uint8_t slotB;    // for swap
  RpDeleteCb deleteCb;
  RpSwapCb swapCb;
  RpQueryCb queryCb;
  RpTextCb textCb;
};

static struct {
  RpQueueEntry entries[RP_QUEUE_SIZE];
  int head = 0;
  int tail = 0;
  int count = 0;

  bool enqueue(const RpQueueEntry &e) {
    if (count >= RP_QUEUE_SIZE) return false;
    entries[tail] = e;
    tail = (tail + 1) % RP_QUEUE_SIZE;
    count++;
    return true;
  }

  RpQueueEntry* peek() {
    if (count == 0) return nullptr;
    return &entries[head];
  }

  void dequeue() {
    if (count == 0) return;
    entries[head].type = RQ_NONE;
    head = (head + 1) % RP_QUEUE_SIZE;
    count--;
  }
} rpQueue;

// ── Pending RP2040 response tracking ──
// For binary responses (delete, swap, query), we use simple pending flags.
// The onMessage callback sets these; the queue processor checks and dispatches.
static struct {
  bool waiting = false;
  uint8_t expectedType;  // MSG_RESP_DELETE_OK, MSG_RESP_SWAP_OK, MSG_RESP_COUNT, etc.
  uint8_t responseValue;
  bool gotResponse = false;
  bool gotError = false;
  unsigned long startTime;
} rpPending;

// ── RP2040 upload task state ──
static struct {
  bool active = false;
  uint8_t slot;
  char filePath[32];
  uint8_t startMsgType;  // MSG_UPLOAD_START
  RpUploadCb callback;
  SemaphoreHandle_t readySem;
  SemaphoreHandle_t doneSem;
  bool readyReceived;
  bool doneReceived;
  bool errorReceived;
} rpUpload;

// Forward declarations
void onRpMessage(ProtoLink *link, const uint8_t *data, uint16_t len);
void rpProcessQueue();

void sendMapToRP() {
  char buf[20];
  snprintf(buf, sizeof(buf), "MAP:%d,%d", flavor1Image, flavor2Image);
  protoRP.sendText(buf);
}

// Queue helper functions
void rpQueueText(const char *text, RpTextCb cb = nullptr) {
  RpQueueEntry e;
  e.type = RQ_TEXT;
  strncpy(e.text, text, RP_TEXT_MAX - 1);
  e.text[RP_TEXT_MAX - 1] = '\0';
  e.textCb = cb;
  rpQueue.enqueue(e);
}

void rpQueueDelete(uint8_t slot, RpDeleteCb cb = nullptr) {
  RpQueueEntry e;
  e.type = RQ_DELETE;
  e.slot = slot;
  e.deleteCb = cb;
  rpQueue.enqueue(e);
}
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

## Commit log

2026-03-07 Dual-flavor soda maker with proportional flow-rate dispensing
    Two-flavor system using L298N motor drivers, flow meter pulse detection,
    and a pump duty-cycle state machine that scales on/off timing proportionally
    to detected water flow rate (1-6 pulses/50ms). Includes cooldown logic to
    cleanly handle flow cessation without jitter.
    [main.cpp]
2026-03-07 Restructure loop around pump state machine
    Reorganize loop into four clear sections: read inputs, pump state
    machine, valve control, LED control. Rename CYCLE_* to PUMP_*, add
    PUMP_PRIME as its own state, replace dispensing/shouldDispense with
    direct valve control derived from pump state. No behavioral changes.
    [main.cpp]
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2026-03-07 Replace 4 recipe constants with single FLAVOR_RATIO knob
    FLAVOR_RATIO sets the flavor-to-water ratio in 1:X notation
    (lower = more flavor). Range: 6 (constant on) to ~24 (hard
    limit floor), default 20. Duty cycle ratio across flow rates
    is preserved at any setting. Adds computeCycleTiming() helper
    to eliminate duplicated timing calculation.
    [main.cpp]
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2026-03-10 Add NVS runtime config, UART command parser, and 240x240 bitmaps
    Replace hardcoded #define flavor config with NVS-backed runtime
    variables. Add bidirectional UART command parser (GET_CONFIG, SET,
    SAVE) on Serial1 for upcoming ESP32-S3 config display, also
    accessible via USB Serial Monitor for testing. Generate 240x240
    RGB565 bitmap headers from source PNGs for the S3 round display.
    [main.cpp, png_to_rgb565.py]
2026-03-10 Add serial integration test for config UART commands
    Tests GET_CONFIG, SET with valid/invalid/boundary values, SAVE,
    and NVS persistence across reboot. Restores defaults after run.
    [test_serial.py]
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2026-03-12 Add LVGL-based menu UI with touch, circular images, and custom font
    Phase 5: Replaced Arduino_GFX direct drawing with LVGL for proper
    Montserrat font kerning. Browse mode shows small circular image or
    ratio with nav dots; edit mode zooms in (full image or 64px ratio).
    Touch tap (CST816D) replaces sticky button for mode switching.
    Gray=browsing, white=editing color pattern throughout.
    [main.cpp]
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2026-03-13 Fix UART pin assignments for ESP32-S3 config link
    Move CONFIG_TX from GPIO 2 to GPIO 15 on ESP32 to avoid boot-strap
    conflict (GPIO 2 must be LOW to flash; CrowPanel level shifter
    pulls it HIGH). LED_FLAVOR2 moves to GPIO 2. Add explicit pin
    config for Serial0 on ESP32-S3 (RX=44, TX=43) since defaults
    don't match the CrowPanel J34 UART connector wiring.
    [main.cpp]
2026-03-13 Clean up firmware comments and update README for 3-MCU architecture
    Remove migration-history comments, fix inaccurate COOLDOWN timing comment,
    add explicit font config, and update README to document the full ESP32 +
    RP2040 + ESP32-S3 system with runtime config protocol.
    [main.cpp]
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2026-03-13 Fix ESP32-S3 display: correct product name, link, and price
    The board is a Meshnology ESP32-S3 Round Rotary Display ($47.76,
    B0G5Q4LXVJ), not an Elecrow CrowPanel. Updated README parts list,
    cost breakdown, and source code comments.
    [main.cpp]
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2026-03-13 Fix bidirectional UART: drain stale RX bytes, add retry logic
    GPIO 35 (ESP32 RX from RP2040) has no pull-up and floats until
    the RP2040 initializes its SerialPIO TX pin, causing noise bytes
    to accumulate in Serial2's RX buffer during boot. This produced
    garbage responses (FF 00 FC 00 FF 00) instead of valid protocol
    data.
    Changes:
    - Drain Serial2 RX buffer before sending QUERY_COUNT
    - Add Serial2.flush() after write to ensure TX completes
    - Return bool from queryImageCount() for retry logic
    - Increase boot delay to 3s (handles first-boot LittleFS seeding)
    - Add 3-attempt retry loop in setup()
    - Include orange_crush.png test image (verified upload works)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
    [main.cpp]
2026-03-13 Add image management: delete, swap, labels for RP2040 display
    Add delete-with-shift, swap, and label system to RP2040 firmware so
    images can be reordered and identified without physical display access.
    ESP32 bridges these commands over UART. Python tool gains --list,
    --delete, --swap, --label flags and auto-labels uploads from filename.
    [main.cpp, upload_image.py]
2026-03-13 Fix LIST, DELETE_IMG, SWAP_IMG command parsing bugs
    Fix \r in LIST command: ESP32 println sent \r\n but RP2040 strcmp
    expected exact "LIST". RP2040 parser now treats \r as line terminator.
    ESP32 also changed to print("LIST\n") without \r.
    Fix off-by-one in DELETE_IMG and SWAP_IMG: strncmp length didn't
    include the trailing colon, causing atoi to parse ":N" instead of "N".
    [main.cpp]
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2026-03-13 Add LittleFS image storage to ESP32-S3 config display (Phase 5)
    Replace compiled PROGMEM images on the S3 with LittleFS storage matching
    the RP2040 pattern. Add binary upload protocol, delete, swap, and label
    support. ESP32 gains S3 bridge mode and 6 new commands (UPLOAD_S3_IMG,
    QUERY_S3_IMAGES, LIST_S3_IMAGES, DELETE_S3_IMG, SWAP_S3_IMG, SET_S3_LABEL).
    Serial1 baud bumped 9600→38400. Python tool enhanced with --target
    (rp2040/s3/both) and --sync to push manifest.json to devices.
    [partitions_s3.csv]
2026-03-13 Add ESP32 as authoritative image store with boot sync (Phase 6)
    ESP32 now stores both RP2040 (128x115) and S3 (240x240) images in its
    own LittleFS. On boot, compares counts with each device and re-uploads
    if mismatched — no computer needed for device recovery after reset.
    - Custom partition table: 576KB app, 3.4MB LittleFS (23 image slots)
    - Store-mode binary upload receiver (same protocol as display devices)
    - Push-to-device: streams from ESP32 LittleFS to device UART
    - Boot sync: count comparison, full re-upload on mismatch
    - New commands: STORE_RP_IMG, STORE_S3_IMG, STORE_LABEL, LIST_STORE,
    PUSH_TO_DEVICES, SYNC_DEVICES, DELETE_STORE_IMG
    - Python tool: --sync stores on ESP32 then pus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
    [partitions_esp32.csv]
2026-03-13 Add first-boot detection, factory defaults, and LittleFS config
    Move user config from NVS to LittleFS. Factory defaults JSON is compiled
    into firmware via embed_txtfiles and parsed with ArduinoJson at boot.
    First-boot detection compares __DATE__/__TIME__ version string in LittleFS
    to reset config on firmware update while preserving images.
    - images/factory_defaults.json: default labels, ratios, image mappings
    - platformio.ini: embed factory_defaults.json, add ArduinoJson dep
    - src/main.cpp: applyFactoryDefaults(), checkFirstBoot(), loadUserConfig(),
    saveUserConfig(), FACTORY_RESET command, force push on first boot
    - tools/upload_image.py: --build-data generates data/ for uploadfs
    - .gitig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
    [main.cpp, upload_image.py]
2026-03-13 Fix first-boot detection: use pre-build generated timestamp
    PlatformIO's SCons build system uses content hashing, so __DATE__/__TIME__
    wouldn't change across builds when source was unchanged. Replace with a
    pre-build script (pre_build.py) that generates src/fw_version.h with a
    fresh timestamp on every build, ensuring first-boot detection triggers
    reliably after every firmware flash.
    [main.cpp]
2026-03-13 Fix factory defaults not updating store image count
    applyFactoryDefaults() was setting labels and config but not updating
    espNumImages or persisting to meta.txt. On first boot, espNumImages
    stayed at 0 (never loaded), so the force push never ran. On subsequent
    boots, bootSync read the old count from meta.txt and pushed all images
    including ones not in factory defaults.
    Now applyFactoryDefaults() also sets espNumImages to the factory count
    and saves both meta.txt and labels.txt, ensuring devices get exactly
    the factory image set.
    [main.cpp]
2026-03-13 Fix S3 sync: init device counts to 0, add UART parser reset
    Two bugs caused the S3 to keep stale images after factory defaults:
    1. numImages/numS3Images initialized to 3 — when boot UART queries
    failed, the default matched espNumImages (also 3), creating a
    false "in sync" that skipped the push. Changed to 0 so failed
    queries always trigger a mismatch and force push.
    2. ESP32 boot noise on GPIO 15 (TX) injects garbage into the S3's
    UART parser, leaving it stuck in binary mode. Added resetS3Parser()
    that sends 150 zero bytes (overflowing the 142-byte binary buffer
    to reset inBinary=false) followed by \n (clearing any partial text
    line). Called once at boot before the f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
    [main.cpp]
2026-03-13 Delete extra device image slots after push
    pushAllToDevice() was pushing espNumImages images but not deleting
    pre-existing higher slots. Devices count consecutive files, so the
    old slot (e.g. orange_crush at slot 3) persisted and was still shown.
    After pushing, now repeatedly send CMD_DELETE_IMAGE for slot
    espNumImages until the device rejects it (count already matches).
    This trims any leftover images from before the factory reset.
    [main.cpp]
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2026-03-14 S3 BLE bridge + iOS config UI with image list
    S3 firmware:
    - Replace BLE echo with UART command forwarding (BLE<->ESP32 bridge)
    - Handle LIST command locally on S3 (image names stored in S3 LittleFS)
    - Forward CONFIG/OK/ERR/IMG responses from ESP32 back to BLE client
    iOS app:
    - Add ConfigView with Flavor 1/2 image and ratio controls (steppers)
    - Add ImageListView showing all images with F1/F2 usage badges
    - BLEManager now parses CONFIG: responses and IMG: image lists
    - Auto-requests config on connect, sends SET/SAVE commands
    [main.cpp]
2026-03-14 BLE image download + fix carousel swipe + config polling
    - Add GETIMG:N command: streams RGB565 image data over BLE in
    240-byte chunks with IMGSTART/IMGEND framing
    - Non-blocking: sends 4 chunks per loop iteration
    - BLEManager receives binary image chunks, converts RGB565 to
    UIImage, caches per slot. Auto-downloads all images after LIST.
    - Add 2-second config polling to stay synced with S3 knob changes
    - Fix carousel: use simultaneousGesture for tap (was blocking drag),
    apply dragOffset live during onChanged for smooth finger tracking,
    restore nav dots
    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
    [main.cpp]
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2026-03-14 Fix carousel, image colors, scanning, and BLE reliability
    Carousel: Move title + dots inside each TabView page so they
    slide with content. TabView fills full screen for swipe anywhere.
    Remove text labels below images to match S3 interface.
    Images: Fix RGB565 to little-endian (matches struct.pack("<H")).
    Slow down BLE chunk rate (1 chunk/loop, 20ms delay) to reduce
    notification packet loss.
    Scanning: Continuous auto-retry with hints after 10 seconds,
    no more dead "not found" state.
    [main.cpp]
2026-03-14 Switch BLE image transfer from RGB565 to compressed PNG
    - Add pngquant-compressed PNG generation to build_data (3-17KB vs 115KB RGB565)
    - Add GETPNG command to S3 firmware for streaming PNG files over BLE
    - Update iOS app to decode PNG natively (UIImage(data:)) instead of RGB565
    - Fix nav dots: move outside TabView into ZStack overlay so they stay fixed
    [main.cpp, upload_image.py]
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2026-03-14 Fix image download bugs: IMGSTART routing, buffer corruption, PNG lifecycle
    iOS:
    - Don't set imgDownloadSlot in downloadNextImage — wait for IMGSTART
    response. Setting it early caused IMGSTART text to be routed as binary
    image data, corrupting every download.
    - Use isDownloading flag for polling guard instead of imgDownloadSlot.
    S3:
    - Allocate separate bleSendBuf for PNG BLE streaming so display rendering
    (loadImageFromFS) can't overwrite the send buffer mid-transfer.
    - Delete and shift PNG files alongside RGB565 in handleDeleteImage.
    - Swap PNG files alongside RGB565 in handleSwapImages.
    ESP32:
    - Delete and shift PNG files in DELETE_STORE_IMG handler.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
    [main.cpp]
2026-03-14 Fix BLE image downloads, eliminate polling, fix UART protocol corruption
    iOS (BLEManager):
    - Replace polling with push-based config (ESP32 sends CONFIG: after SAVE)
    - Fix double-send on connect (nusReady flag prevents duplicate init)
    - Fix IMGEND race condition (wait for IMGEND before starting next download)
    - Add ERR: handling to skip failed downloads and continue queue
    - Add RX debug logging for all BLE notifications
    iOS (ConfigView):
    - Remove redundant onAppear config/image requests (handled by BLE connect)
    - Fix swipe direction to match iOS convention (left=next, right=previous)
    ESP32 (main.cpp):
    - Push CONFIG: to S3 via UART after SAVE for BLE forwarding
    - Fix pushPngToS3 returning tr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
    [main.cpp]
2026-03-14 Guard renderCircularThumb from corrupting BLE image transfers
    Prevents loadImageFromFS from overwriting imageBuf (which is aliased
    as bleSendBuf) while a BLE image download is in progress. Without this,
    rotating the encoder during a download would corrupt the transfer data.
    [main.cpp]
2026-03-14 Move BLE RX callback I/O to main task for cross-task safety
    BLE RX callback (onWrite) runs on NimBLE task — LittleFS reads and
    Serial0 writes from that context can crash the S3. Callback now sets
    a BleRequest flag + buffers data; processBleRequest() in loop() does
    all file I/O and UART work on the main task.
    [main.cpp]
2026-03-14 Remove imageBuf/bleSendBuf aliasing, stream BLE from file
    Replace bleSendBuf=(uint8_t*)imageBuf aliasing with file-based
    streaming via bleFile handle and 240-byte bleSendChunkBuf. This
    decouples BLE image downloads from display rendering — removes the
    bleImageSending guard from renderCircularThumb().
    [main.cpp]
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2026-03-14 Migrate RP2040 display to SerialTransfer protocol
    Replace hand-rolled STX STX binary parser and text/binary multiplexer
    with SerialTransfer COBS-encoded packets. Remove crc16(), binBuf,
    textBuf, inBinary state, sendBinaryResponse(), tryParseBinaryMessage(),
    and checkUART(). Handler functions now accept extracted fields instead
    of raw message pointers. Text commands (MAP, LABEL, LIST) arrive via
    PKT_TEXT packets.
    [main.cpp]
2026-03-14 Migrate ESP32 Serial2 (RP2040 link) to SerialTransfer
    Replace hand-rolled STX STX binary protocol with SerialTransfer (COBS)
    for all ESP32→RP2040 communication over Serial2. S3 link (Serial1)
    remains on old protocol for now (commit 7).
    - pushImageToDevice(): RP2040 path uses stRP with PKT_UPLOAD_START/
    PKT_CHUNK_DATA/PKT_UPLOAD_DONE, S3 path unchanged
    - deleteLastDeviceImage(): RP2040 path uses stRP with PKT_DELETE_IMAGE
    - All Serial2 text sends (MAP, LABEL, LIST) converted to stSendText()
    - DELETE_IMG/SWAP_IMG/DELETE_STORE_IMG handlers use stRP for RP2040
    - LIST_IMAGES handler polls stRP for PKT_TEXT responses
    - Remove enterUploadMode() bridge mode (replaced by store+push)
    - Remove UPL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
    [main.cpp]
2026-03-14 Migrate S3 config display to SerialTransfer
    Replace hand-rolled STX STX binary protocol and text/binary multiplexer
    with SerialTransfer (COBS) for all ESP32-S3 UART communication.
    - Replace checkUart() text/binary parser with checkSerialTransfer()
    dispatching on packet IDs
    - PKT_UPLOAD_PNG_START (0x07) replaces slot>=100 hack, tracked via
    upload.isPng field
    - Handler signatures take extracted fields instead of raw msg pointers
    - sendBinaryResponse() replaced with stSendResponse()/stSendEmptyResponse()
    - Serial0 text sends (SET, SAVE, GET_CONFIG, LIST responses, BLE forward)
    all use stSendText()
    - Remove crc16(), crc32_update(), binary protocol constants, parser buffers
    - Remove upload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
    [main.cpp]
2026-03-14 Migrate ESP32 Serial1 (S3 link) to SerialTransfer
    Replace all hand-rolled binary protocol on the ESP32↔S3 UART link with
    SerialTransfer (stS3). Key changes:
    - Add stS3 SerialTransfer instance on Serial1
    - Rewrite queryS3ImageCount, pushImageToDevice (S3 path), pushPngToS3,
    deleteLastDeviceImage (S3 path) to use stS3 with packet IDs
    - PKT_UPLOAD_PNG_START (0x07) replaces slot+100 hack for PNG uploads
    - Replace all Serial1 text sends with stSendText(stS3, ...)
    - Replace checkConfigStream(Serial1, ...) with stS3 PKT_TEXT polling
    using StStream wrapper class — routes processConfigCommand output
    to SerialTransfer packets without touching the 475-line function
    - Remove resetS3Parser()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
    [main.cpp]
2026-03-14 Add PUSH_IMG command, remove bridge mode from upload tool
    ESP32 firmware:
    - Add PUSH_IMG:slot:target text command to processConfigCommand
    (pushes a single stored image to rp2040/s3/both)
    upload_image.py:
    - Remove upload() function (bridge mode — no longer exists on ESP32)
    - Remove upload_image_file(), sync_device(), wait_for_bridge_exit()
    - Single-image upload now uses store+push: stores both resolutions +
    PNG on ESP32, sets label, then sends PUSH_IMG:slot:both
    - Add push_single_image() helper
    - --sync and --push flows unchanged
    - USB binary protocol (store mode) unchanged
    [main.cpp, upload_image.py]
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2026-03-14 Fix SerialTransfer zero-length payload bug
    SerialTransfer's parser rejects payload length 0 as PAYLOAD_ERROR,
    so stSendEmptyResponse and PKT_QUERY_COUNT packets were silently
    dropped. Send 1 dummy byte instead of 0 in all zero-length sends.
    [main.cpp]
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2026-03-14 Add ESP32 upload receiving from S3 + FINALIZE_UPLOAD command
    ESP32 can now receive SerialTransfer upload packets (PKT_UPLOAD_START,
    PKT_UPLOAD_PNG_START, PKT_UPLOAD_RP_START, PKT_CHUNK_DATA, PKT_UPLOAD_DONE)
    on the S3 link, storing files at the correct paths (/s3_imgNN.bin,
    /s3_pngNN.png, /rp_imgNN.bin). Uses separate temp file /tmp_s3.bin to
    avoid conflicts with USB store mode.
    FINALIZE_UPLOAD:slot:label text command commits a phone-uploaded image:
    updates metadata, pushes RP2040 RGB565 to RP2040, pushes labels to all
    devices, and sends CONFIG: update to S3 for BLE forwarding.
    [main.cpp]
2026-03-14 Add S3 BLE upload receiver for phone image uploads
    BLE RX callback accumulates binary upload data into imageBuf (115KB)
    using the existing cross-task safety pattern: BLE callback does memcpy
    only, loop() handles CRC verification and LittleFS writes.
    New BLE protocol:
    IMG_UPLOAD:slot=N,type=png|s3|rp,size=X,crc32=0xY[,label=Z]
    -> UPLOAD_READY -> binary chunks -> IMG_OK or IMG_ERR
    S3 stores PNG and S3 RGB565 locally, skips RP2040 RGB565 (not needed
    on S3). Forwarding to ESP32 via SerialTransfer added in next commit.
    [main.cpp]
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2026-03-14 Fix BLE advertising failure: move imageBuf to PSRAM
    The 115KB static imageBuf was consuming most of the ESP32-S3's internal
    SRAM, leaving only ~5KB free heap — not enough for NimBLE to advertise.
    Switch board definition to esp32-s3-devkitc1-n8r8 (enables 8MB PSRAM)
    and allocate imageBuf via ps_malloc() at setup, freeing ~175KB heap for
    the BLE stack. Also reduce BLE notification chunk size to 180 bytes to
    fit within the negotiated ATT MTU payload.
    [main.cpp]
2026-03-14 Fix BLE image upload: iOS 3x scale bug, S3 validation, pushPng honesty
    Three bugs fixed:
    1. iOS ImageProcessor used device screen scale (3x on iPhone) making
    240x240 images actually 720x720 pixels — PNGs were 722KB instead
    of ~20KB. Fixed by setting UIGraphicsImageRendererFormat.scale = 1.0.
    2. S3 upload rejection now includes details in the error response
    (slot, size, max) for easier debugging.
    3. pushPngToS3() was returning true when PNG file didn't exist on
    ESP32, hiding boot sync failures. Now returns false so callers
    and logs accurately report the state.
    [main.cpp]
2026-03-14 Fix GET_CONFIG lost during ESP32 boot sync
    The S3 was forwarding GET_CONFIG to ESP32 via SerialTransfer, but
    during boot sync the ESP32 sits in waitStResponse() loops that discard
    unexpected packets. If the phone connects while boot sync is running,
    its GET_CONFIG is consumed and never processed.
    Fix: S3 now responds to GET_CONFIG directly from cached config values
    (which are synced at boot), then also forwards to ESP32 for a fresh
    push. This ensures the phone always gets an immediate response.
    Also moved config state variables earlier in the file to be accessible
    from processBleRequest().
    [main.cpp]
2026-03-14 Add Factory Reset page to S3 config UI (5th dot)
    Scroll to the 5th page to see a refresh icon, tap to enter
    confirmation ("Tap to Confirm" in red), tap again to send
    FACTORY_RESET to ESP32 via UART. UI locks during reset and
    re-syncs config via GET_CONFIG when complete.
    [main.cpp]
2026-03-14 Fix delete image: response-driven refresh, config persist, label removal
    - iOS: Parse OK:STORE_DELETED response to update numImages and clear
    image cache instead of using a blind 2-second timer
    - ESP32: Save adjusted flavor references after delete and push CONFIG
    update to S3/BLE so all devices stay in sync
    - S3: Add memory barrier between bleForwardBuf write and request flag
    to prevent cross-task race on dual-core ESP32-S3
    - UI: Remove image labels from list rows and delete confirmation
    [main.cpp]
2026-03-14 Make factory reset metadata-only, protect factory images from deletion
    ESP32 changes:
    - Add factoryImageCount (parsed from factory_defaults.json on every boot)
    - DELETE_STORE_IMG rejects slots < factoryImageCount
    - FACTORY_RESET no longer pushes images — just resets config/labels,
    deletes user_config.txt, cleans up orphaned user-image files, and
    sends lightweight CONFIG + MAP + labels to devices
    S3 changes:
    - parseConfigResponse now parses numImages from CONFIG string so the
    S3 stays in sync after factory reset without needing image re-push
    Factory images (slots 0..factoryImageCount-1) can never be deleted,
    so factory reset is safe and instant — no UART image transfers needed.
    C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
    [main.cpp]
2026-03-14 Rename manifests: factory_manifest.json + user_manifest.json, split sync flags
    - Rename factory_defaults.json → factory_manifest.json (add slots field
    so upload script can use it directly, keep images/config fields for
    firmware embedding)
    - Rename manifest.json → user_manifest.json (dev/test, includes 4th image)
    - Replace --sync with --sync-factory and --sync-user flags
    - --build-data now uses factory_manifest.json
    - Update platformio.ini embed path and ESP32 asm symbol name
    [main.cpp, upload_image.py]
2026-03-14 Rework 5th dot as Settings submenu with Back, Factory Reset, About
    Settings page shows gear icon in browse mode. Tap enters a sub-menu
    with three items navigable via rotary encoder:
    - Back: returns to main menu
    - Factory Reset: tap shows "Tap to Confirm" (red), tap again executes
    - About: shows build date
    Factory reset confirmation exits to main menu on completion.
    Multiple taps + rotary scrolls required to reach factory reset,
    preventing accidental triggers.
    [main.cpp]
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2026-03-15 Settings: vertical list UI, Yes/No confirmation for factory reset
    - Settings sub-menu renders all items as a vertical list with the
    selected item in white and others in dark gray
    - Factory Reset confirmation shows Yes/No list (defaults to No)
    instead of a one-option "Tap to Confirm"
    - About shows build date inline when selected
    - Back is plain text (no arrow icon)
    [main.cpp]
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
